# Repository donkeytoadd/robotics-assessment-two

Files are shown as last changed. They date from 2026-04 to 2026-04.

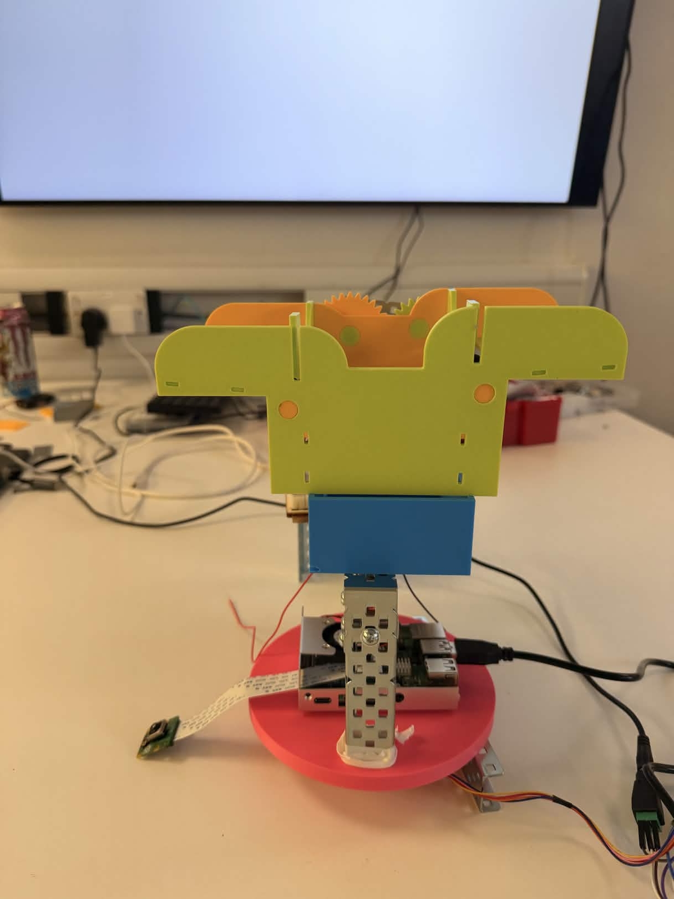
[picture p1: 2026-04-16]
design documents:WIPs/IMG_0576.jpg

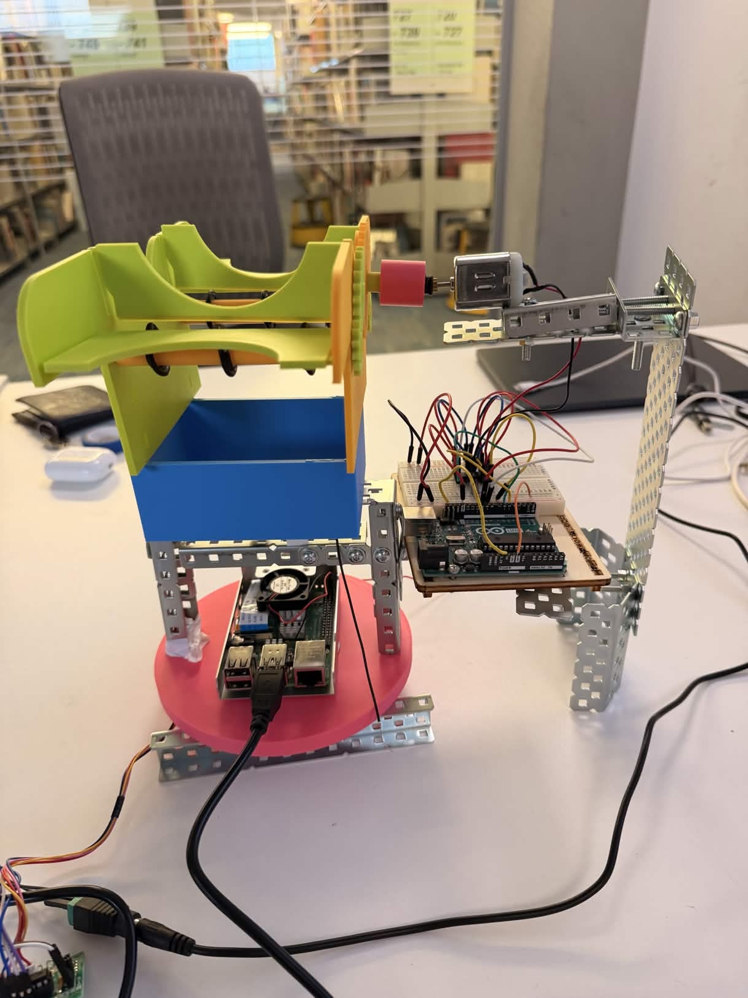
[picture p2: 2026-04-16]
design documents:WIPs/IMG_0577.jpg

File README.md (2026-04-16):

# Automated Card Shuffler & Dealer

An Arduino + Raspberry Pi project that automates shuffling and dealing a deck of playing cards. The machine scans around the table to detect and locate players, then deals cards to each player in turn.

## Overview

The machine is built in three stacked layers:

```text
┌─────────────────────────┐
│      Card Shuffler      │  ← DC motor splits & shuffles half-decks
├─────────────────────────┤
│    Card Magazine        │  ← Holds shuffled deck; DC motor dispenses one card at a time
├─────────────────────────┤
│  Rotating Platform      │  ← Stepper motor rotates 360°; Raspberry Pi + PiCamera scans for players
└─────────────────────────┘
```

### Layer 1 - Rotating Platform (bottom)

- **Arduino Uno** drives a stepper motor via pins 8–11
- **Raspberry Pi** (mounted on the platform) runs a YOLOv8 person-detection model via PiCamera2
- On scan start, the platform performs one full 360° rotation; whenever a centered person is detected the Pi requests the current angle from the Arduino and stores it
- After the scan completes, all captured player angles are sent back to the Arduino so the platform can rotate to each player position during dealing

### Layer 2 - Card Magazine (middle)

- Sits directly above the platform
- A **DC motor** (connected via an H-bridge to Arduino pins 9/10) drives a wheel that ejects cards one at a time when a `DISPENSE` command is received

### Layer 3 - Card Shuffler (top)

- A split deck is loaded into two chutes
- A **DC motor** (H-bridge, Arduino pins 5/6) interleaves the two halves when a `SHUFFLE` command is received

### Serial Protocol (Arduino ↔ Raspberry Pi)

| Direction | Message | Meaning |
|---|---|---|
| Arduino → Pi | `SCAN` | Begin 360° scan / player detection |
| Arduino → Pi | `STOP` | Scan complete; send stored angles back |
| Pi → Arduino | `CAPTURE_ANGLE` | Record current platform angle |
| Arduino → Pi | `ANGLE:<n>` | Current angle in degrees |
| Pi → Arduino | `STORED_ANGLES:<a,b,c>` | Comma-separated player angles |
| Pi → Arduino | `SHUFFLE` | Run the shuffler motor |
| Pi → Arduino | `DISPENSE` | Eject one card |

---

## Hardware Requirements

| Component | Quantity | Notes |
|---|---|---|
| Arduino Uno | 1 | - |
| Raspberry Pi (3B+ or 4) | 1 | Must support PiCamera2 |
| Raspberry Pi Camera Module v2/v3 | 1 | |
| Stepper motor + driver | 1 | Platform rotation |
| DC motor (5–9 V) | 2 | One for shuffler, one for dispenser |
| L2983D (or similar) H-bridge | 1–2 | Motor driver for DC motors |
| Push button | 1 | Triggers scan sequence (Arduino digital pin 2) |
| Jumper wires, power supply, frame/chassis | — | |

### Pin Mapping

#### Stepper (platform rotation)

| Arduino Pin | Function |
|---|---|
| 8 | Coil A (IN1) |
| 9 | Coil B (IN2) |
| 10 | Coil C (IN3) |
| 11 | Coil D (IN4) |

> **Note:** the `Stepper` library is initialised with pins in the order `8, 10, 9, 11` to match the coil wiring sequence required for correct rotation direction. See [stepper_controller.cpp](arduino/lib/servo_controller/implementations/stepper_controller.cpp) line 8.

#### DC Motors (H-bridge)

| Arduino Pin | Function |
|---|---|
| 5 | Shuffler — forward |
| 6 | Shuffler — reverse |
| 10 | Dispenser — forward |
| 9 | Dispenser — reverse |

> **Note:** pins 9 and 10 are shared between the stepper driver and the DC motor H-bridge in the current wiring. If both are needed simultaneously, remap one set of pins and update the `#define` values in [dc_motor_controller.h](arduino/lib/dc_motor_controller/headers/dc_motor_controller.h).

#### Button

| Arduino Pin | Function |
|---|---|
| 2 (INPUT_PULLUP) | Scan trigger button |

---

## Software Requirements

### Arduino (PlatformIO)

- [PlatformIO](https://platformio.org/) (VS Code extension recommended)
- Dependencies are managed automatically via `platformio.ini`:
  - `arduino-libraries/Stepper@^1.1.3`

### Raspberry Pi

```text
Python 3.9+
picamera2
opencv-python
ultralytics   (YOLOv8)
pyserial
```

---

## Building & Flashing the Arduino

1. Open the `arduino/` folder in VS Code with the PlatformIO extension installed.
2. PlatformIO will automatically resolve the `Stepper` library dependency.
3. Connect the Arduino Uno via USB.
4. Click **Upload** in PlatformIO (or run `pio run --target upload` in the terminal).
5. Open the Serial Monitor to observe debug output.

```bash
# From the arduino/ directory
pio run --target upload
pio device monitor --baud 9600
```

---

## Setting Up the Raspberry Pi

### 1. Install dependencies

```bash
pip install picamera2 opencv-python ultralytics pyserial
```

### 2. Download the YOLOv8 model

The first run downloads `yolov8n.pt` automatically via `ultralytics`. To pre-download:

```bash
python -c "from ultralytics import YOLO; YOLO('yolov8n.pt')"
```

### 3. Verify the serial port

The Pi communicates with the Arduino over `/dev/ttyACM0`. Confirm the port:

```bash
ls /dev/ttyACM*
```

If the port differs, update line 18 of [main.py](raspberry_pi/main.py):

```python
ser = serial.Serial('/dev/ttyACM0', 9600)
```

### 4. (Optional) Enable the live camera stream

In [main.py](raspberry_pi/main.py), set:

```python
enableCameraFeed = True
```

The annotated stream will be available at `http://<pi-ip>:8080/stream` once running.

### 5. Run

```bash
cd raspberry_pi
python main.py
```

---

## Operating the Machine

### Full Dealing Sequence

1. **Load the deck** — split the deck roughly in half and place each half into the two shuffler chutes at the top of the machine.
2. **Power on** — connect the Arduino and start `main.py` on the Raspberry Pi.
3. **Shuffle** — send `SHUFFLE` over serial (or trigger from the Pi) to interleave the two half-decks. The shuffler motor runs for 5 seconds by default. The shuffled deck drops down into the magazine.
4. **Scan for players** — press the physical button connected to Arduino pin 2. The platform will:
   - Reset to its home position (1° nudge)
   - Send `SCAN` to the Pi to begin person detection
   - Rotate 360° at 10 RPM
   - Send `STOP` when complete; the Pi transmits all detected player angles back to the Arduino
5. **Deal** — send `DISPENSE` for each card. The platform rotates to each player's stored angle before the dispenser motor pulses to eject a single card.

### Manual Serial Commands

Connect a serial terminal to the Arduino or send commands from the Pi:

| Command | Effect |
|---|---|
| `SHUFFLE` | Run shuffler for the configured duration |
| `SHUFFLE_FULL` | Run shuffler at full PWM (255) for 5 s |
| `DISPENSE` | Eject one card (single pulse) |
| `SET_SHUFFLE_SPEED <0-255>` | Set shuffler PWM level |
| `SET_DISPENSE_SPEED <0-255>` | Set dispenser PWM level |
| `SET_SHUFFLE_DURATION <ms>` | Set how long the shuffler runs |
| `SET_DISPENSE_PULSE <ms>` | Set how long each dispense pulse lasts |

### Tuning Motor Parameters

Default values are set in [dc_motor_controller.cpp](arduino/lib/dc_motor_controller/implementations/dc_motor_controller.cpp):

```cpp
shuffleSpeed    = 200;   // PWM 0–255
dispenseSpeed   = 250;   // PWM 0–255
shuffleDuration = 5000;  // milliseconds
dispensePulse   = 300;   // milliseconds
```

These can be changed at runtime with the `SET_*` serial commands above, or adjusted at compile time.

---

## Known Limitations

**Motor torque is insufficient when fully assembled.** When all three layers are stacked (platform + magazine + shuffler), the combined weight exceeds what the current motors can reliably move. Potential remedies:

- Use a higher-voltage, higher-current DC motor for the shuffler and dispenser, and a matched H-bridge capable of supplying the required current.
- Power the motors from a dedicated external supply rather than relying on the Arduino's 5 V rail.
- Reduce the physical weight of the upper layers by redesigning the frame with lighter materials.
- Increase the gear ratio to trade speed for torque.

---

## Project Structure

```text
robotics-assessment-two/
├── arduino/
│   ├── src/
│   │   └── main.cpp                          # Arduino entry point
│   ├── lib/
│   │   ├── dc_motor_controller/
│   │   │   ├── headers/dc_motor_controller.h
│   │   │   └── implementations/dc_motor_controller.cpp
│   │   └── servo_controller/
│   │       ├── headers/
│   │       │   ├── stepper_controller.h
│   │       │   └── digital_button.h
│   │       └── implementations/
│   │           ├── stepper_controller.cpp
│   │           └── digital_button.cpp
│   └── platformio.ini
└── raspberry_pi/
    ├── main.py          # Person detection, serial comms, angle capture
    └── stream_server.py # Optional MJPEG stream server (port 8080)
```

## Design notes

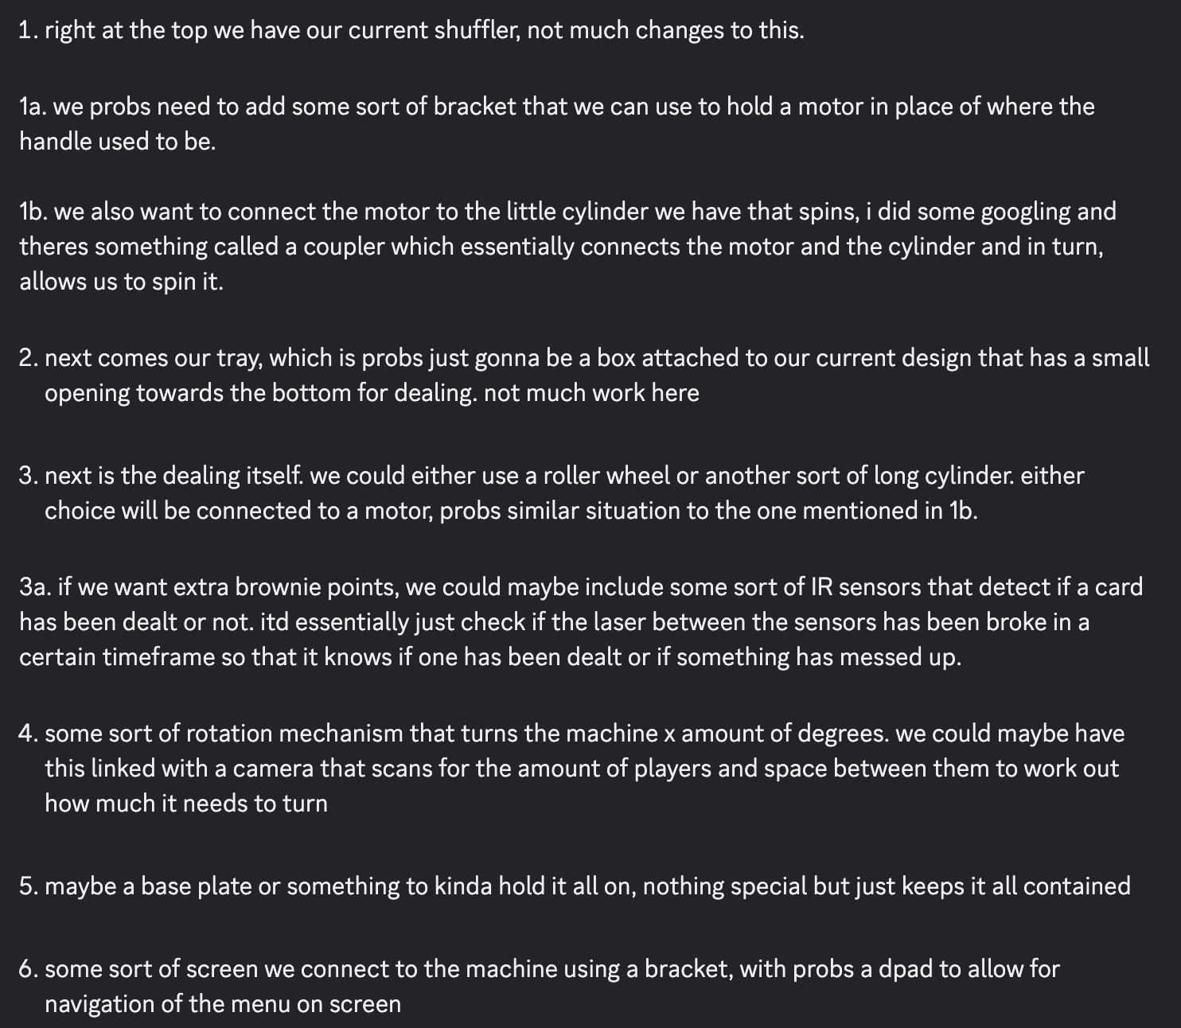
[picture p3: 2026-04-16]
design documents:WIPs/plan from group chat.png

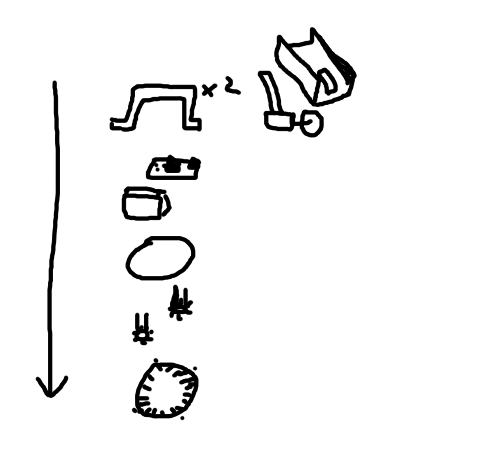
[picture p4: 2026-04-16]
design documents:WIPs/bogdan plan.png

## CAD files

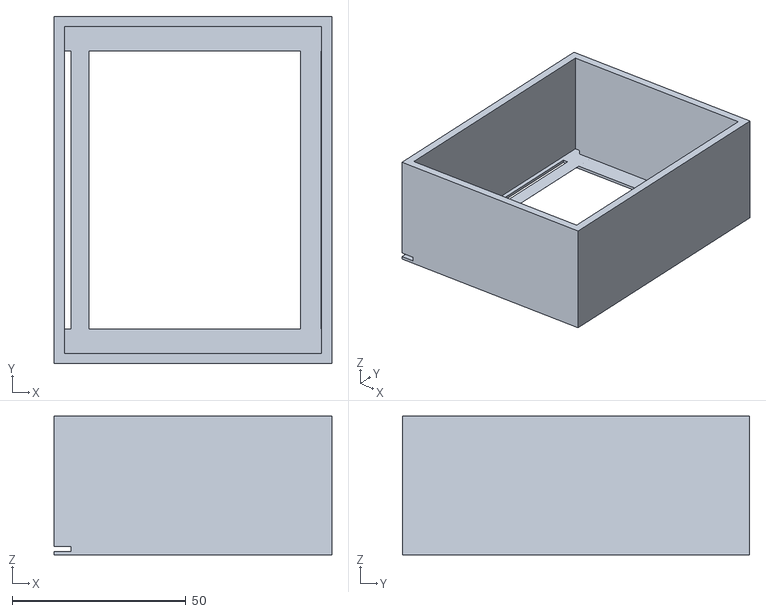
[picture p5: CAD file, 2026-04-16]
3d models/Card Magazine (3).stl
80.0 x 100.0 x 40.0

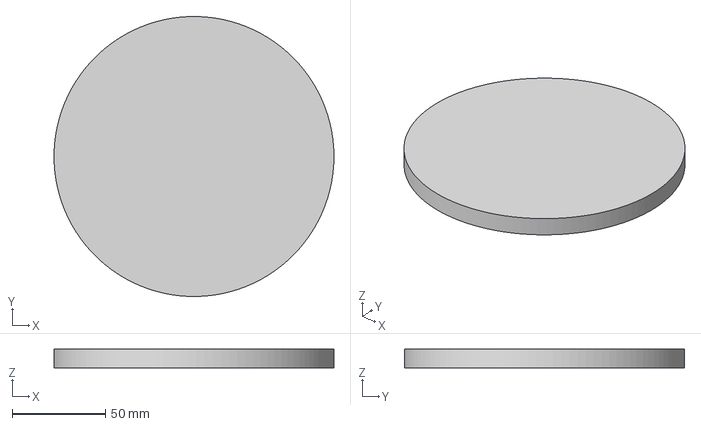
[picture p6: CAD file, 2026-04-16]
3d models/turntable-models/motor_turntable.3mf
150.0 x 150.0 x 10.0 mm

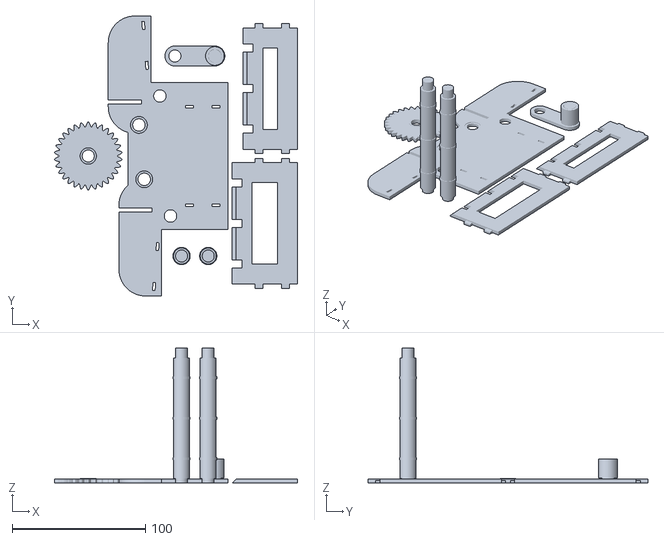
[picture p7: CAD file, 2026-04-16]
3d models/card.shuffler.v2b.stl
182.4 x 210.0 x 101.2

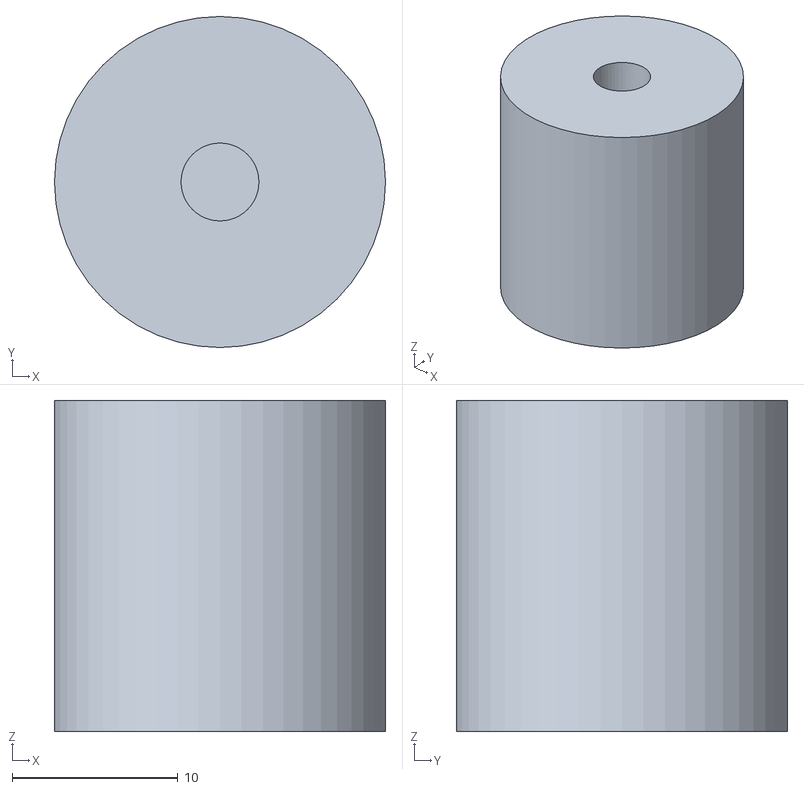
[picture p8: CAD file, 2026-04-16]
3d models/servo_coupler.stl
20.0 x 20.0 x 20.0

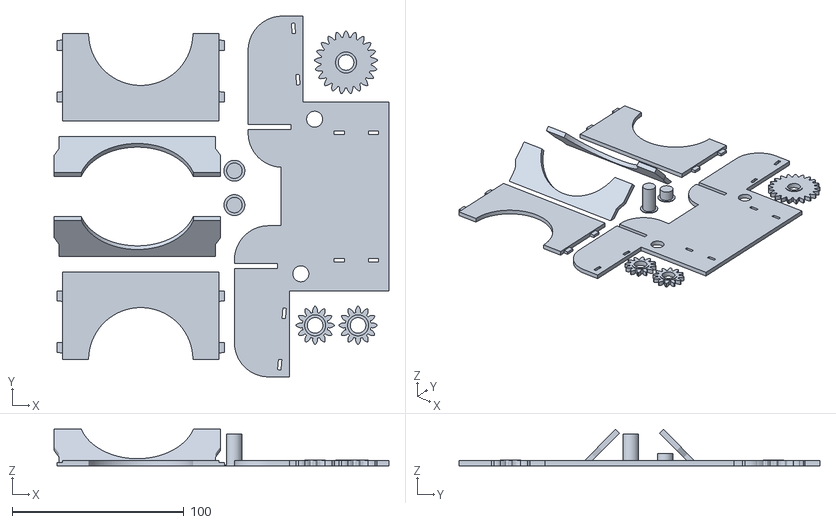
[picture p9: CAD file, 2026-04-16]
3d models/card.shuffler.v2a.stl
195.0 x 210.0 x 21.4

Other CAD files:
3d models/turntable-models/motor_turntable.stl

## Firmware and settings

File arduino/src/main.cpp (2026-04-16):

#include <Arduino.h>
#include <headers/stepper_controller.h>
#include <headers/digital_button.h>
#include <headers/dc_motor_controller.h>

DigitalButton scanButton = DigitalButton();
StepperController stepMotor;
DCMotorController dcMotor;

void handleScanPress();
void handleSerialCommands();

String inputBuffer = "";

void setup()
{
  Serial.begin(9600);

  // initialise DC motors with pin modes and ensure they start in a stopped state
  dcMotor.begin();

  // configure the scan button pin and register the press handler
  scanButton.begin();
  scanButton.onPress(handleScanPress);
}

void loop()
{
  // check button state for a press event
  scanButton.loop();
  // check for incoming serial commands from the Raspberry Pi
  handleSerialCommands();
  // advance the stepper motor by one step toward its current target (non-blocking)
  stepMotor.TurnStep();
}

// notifies the Raspberry Pi to begin scanning, then rotates the turntable 360 degrees.
// a short delay is added before the motor starts so the Pi has time to enter scan mode
void startScan()
{
  Serial.println("SCAN");
  delay(200);
  stepMotor.SetTarget(360, []()
                      { Serial.println("STOP"); }, 10);
}

// on button press, the motor first resets to position 1 (near-zero) before starting the scan,
// ensuring each scan begins from a consistent home position
void handleScanPress()
{
  stepMotor.SetTarget(1, []()
                      { startScan(); }, 15);
}

// queue used to store the angles received from the Raspberry Pi for motor positioning
int angleQueue[50];
int queueSize = 0;
int queueIndex = 0;

// is called when the motor finishes moving to an angle, moves to the next queued angle if one exists,
// or reports ALL_ANGLES_DONE to the Pi when all positions have been visited
void onAngleComplete()
{
  Serial.println("Queue index: " + String(queueIndex) + ", Queue size: " + String(queueSize));
  if (queueIndex < queueSize)
    stepMotor.SetTarget(angleQueue[queueIndex++], onAngleComplete);
  else
    Serial.println("ALL_ANGLES_DONE");
}

// parses a list of angles from the Pi and loads them into the queue,
// then starts movement to the first angle
void handleStoredAngles(String data)
{
  queueSize = 0;
  queueIndex = 0;
  int start = 0;
  int commaIndex = -1;
  do
  {
    commaIndex = data.indexOf(',', start);
    // extract each token between commas
    String angleStr = (commaIndex == -1)
                          ? data.substring(start)
                          : data.substring(start, commaIndex);

    angleQueue[queueSize++] = angleStr.toInt();
    start = commaIndex + 1;
  } while (commaIndex != -1);

  if (queueSize > 0)
    stepMotor.SetTarget(angleQueue[queueIndex++], onAngleComplete);
}

// reads a line from serial, then routes to the appropriate handler.
// CAPTURE_ANGLE and STORED_ANGLES are stepper commands; everything else is forwarded to the DC motor controller
void handleSerialCommands()
{
  if (Serial.available() > 0)
  {
    String cmd = Serial.readStringUntil('\n');
    cmd.trim();

    if (cmd == "CAPTURE_ANGLE")
    {
      // respond with the turntable's current angle so the Pi can record it
      Serial.println("ANGLE:" + String(stepMotor.CurrentAngle()));
    }
    else if (cmd.startsWith("STORED_ANGLES:"))
    {
      String data = cmd.substring(14);
      Serial.println("Stored ANGLES: " + data);
      handleStoredAngles(data);
    }
    else
    {
      dcMotor.handleCommand(cmd);
    }
  }
}

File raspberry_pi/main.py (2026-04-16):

print("Running on Raspberry Pi")
import serial
from picamera2 import Picamera2
import cv2
from ultralytics import YOLO
import time
import threading
import stream_server

enableCameraFeed = False
if(enableCameraFeed):
    stream_server.start()

# list of angles where a person was detected during a scan, this is sent to the Arduino after STOP is received
angles = []

# tracks the last time a detection was acted on, used to enforce a cooldown between captures
last_sent = 0
# seconds to wait between successive angle captures
cooldown = 1

# open serial connection to the Arduino
ser = serial.Serial('/dev/ttyACM0', 9600)
isScanning = False

# configure the camera for a small frame to maintain performance
picam2 = Picamera2()
picam2.configure(picam2.create_preview_configuration(
    main={"format": "RGB888", "size": (320, 240)}
))
picam2.start()
time.sleep(2)

# load the YOLOv8 model
model = YOLO("yolov8n.pt")

# frame counter used to throttle how often YOLO inference is run
counter = 0

# latest_frame is written by the camera thread and read by the main loop
# frame_lock ensures reads and writes don't race
latest_frame = None
frame_lock = threading.Lock()

# runs in a background thread to continuously capture frames from the camera.
# if the stream feed is enabled, also runs inference and pushes annotated frames to the server
def camera_thread():
    global latest_frame
    while True:
        frame = picam2.capture_array()
        with frame_lock:
            latest_frame = frame
        if(enableCameraFeed):
            results = model(frame, verbose=False, imgsz=256, classes=[0])
            stream_server.set_frame(results[0].plot())

t = threading.Thread(target=camera_thread, daemon=True)
t.start()

# serialises the collected angles as a comma-separated string and sends them to the Arduino.
# the Arduino will then move the turntable to each angle in sequence to dispense cards
def sendStoredAngles():
    if angles:
      message = ",".join(str(a) for a in angles)
      ser.write(f"STORED_ANGLES:{message}\n".encode())
      angles.clear()
    else:
      print("No angles to send.")

# reads one line from serial if available and handles scan lifecycle commands from the Arduino.
# SCAN/STOP control the scanning state, ANGLE responses are stored for later
def handle_serial_commands():
    global isScanning
    if ser.in_waiting > 0:
        line = ser.readline().decode().strip()
        print("CMD:", line)
        if line == "SCAN":
            isScanning = True
            print("Scan mode STARTED")
        elif line == "STOP":
            isScanning = False
            print("Scan mode STOPPED")
            time.sleep(1)
            sendStoredAngles()
        elif line.startswith("ANGLE:"):
            angle = int(line.split(":")[1])
            angles.append(angle)
            print(f"Captured angle: {angle}")
            return

# checks whether any detected person's bounding box centre falls within tolerance pixels of the horizontal centre of the frame
def is_centered_human(results, frame_width, tolerance=80):
    center_x = frame_width / 2
    for box in results[0].boxes:
        cls = int(box.cls[0])
        if model.names[cls] != "person":
            continue
        x1, y1, x2, y2 = box.xyxy[0].tolist()
        if abs((x1 + x2) / 2 - center_x) <= tolerance:
            return True
    return False

# grabs the latest camera frame and runs YOLO inference on every 3rd call
# returns True if a centred person is detected in the current frame
def detect_human():
    global counter
    with frame_lock:
        if latest_frame is None:
            return False
        frame = latest_frame.copy()

    counter += 1
    if counter % 3 != 0:
        return False

    results = model(frame, verbose=False, imgsz=256)
    if(enableCameraFeed):
        stream_server.set_frame(results[0].plot())
    return is_centered_human(results, frame.shape[1])

# sends a CAPTURE_ANGLE command to the Arduino, which responds with the turntable's current angle
def captureAngle():
    global angles
    ser.write(b"CAPTURE_ANGLE\n")

# main loop which continuously polls for serial commands and, when in scan mode,
# checks for human detections and capture the turntable angle
while True:
    handle_serial_commands()
    if isScanning:
      if detect_human():
          if time.time() - last_sent > cooldown:
              print("HUMAN DETECTED")
              captureAngle()
              last_sent = time.time()

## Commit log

2026-03-14 this is a test to see if i can commit using raspberry pi terminal
2026-03-21 added stepper controller library, allows control of stepper motor.
2026-04-14 feat: add raspberry pi implementation
2026-04-14 raspberry pi implementation by Bogdan Kwasnicki
2026-04-14 added button to start scan and refactored code to send commands to raspberry pi, as well as listen to pi
2026-04-15 implement code to power dc motors. reads serial cmd to look for either a dispense or shuffle command, and then powers the relevant motor. also did small refactor to main.cpp to structure functions be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
2026-04-16 add 3d models, design documents/planning documents, and work in progress images/videos
    [Card Magazine (3).stl, card.shuffler.v2a.stl, card.shuffler.v2b.stl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]
2026-04-16 Added custom fusion made motor turntable models
    [motor_turntable.3mf, motor_turntable.stl]
